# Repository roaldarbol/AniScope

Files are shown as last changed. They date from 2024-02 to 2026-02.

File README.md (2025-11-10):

<h1 align="center">AniScope</h1>
<p align="center">



</p>

<p align="center">
  
</p>
<p align="center">
  <b>A modular ethoscope for customised behavioural experiments with tiny animals.</b><br>
</p>

# Features
Due to its modular design, AniScope is easy to modify:
- Easy customization with the OpenSCAD Customizer
- Create and use presets
- Multiple arenas available
- Goes hand-in-hand with [BeeHive](https://github.com/BeeHive-org/BeeHive) for electronics

# Quick start
1. [Download OpenSCAD](https://openscad.org/downloads.html)
2. Download this repository
    - *From Github: click `Code`->`Download Zip`*
    - *From command line: `git clone https://github.com/roaldarbol/AniScope.git`*
3. Open OpenSCAD
4. Open `aniscope.scad`
5. Enable the Customizer
    - `Window` -> `Customizer`
6. For the best experience, change `Show description`to `Description only`. 

# Acknowledgements
The term ethoscope was coined by Quentin Geissman and Giorgio Gilestro (see their [Ethoscope](https://giorgiogilestro.notion.site/giorgiogilestro/Ethoscope-User-Manual-a9739373ae9f4840aa45b277f2f0e3a7)). The philosophy behind the modularity also takes great inspiration from the [UC2](https://github.com/openUC2/UC2-GIT) modular microscope and [BeeHive](https://github.com/BeeHive-org/BeeHive) for electronics.

# Tips
For keeping track of magnet polarities, we recommend the [Magic Magnet tool](https://www.printables.com/model/409283-the-magic-magnet-tool).

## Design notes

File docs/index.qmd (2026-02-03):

<h1 align="center">AniScope</h1>
<p align="center">


</p>

<p align="center">
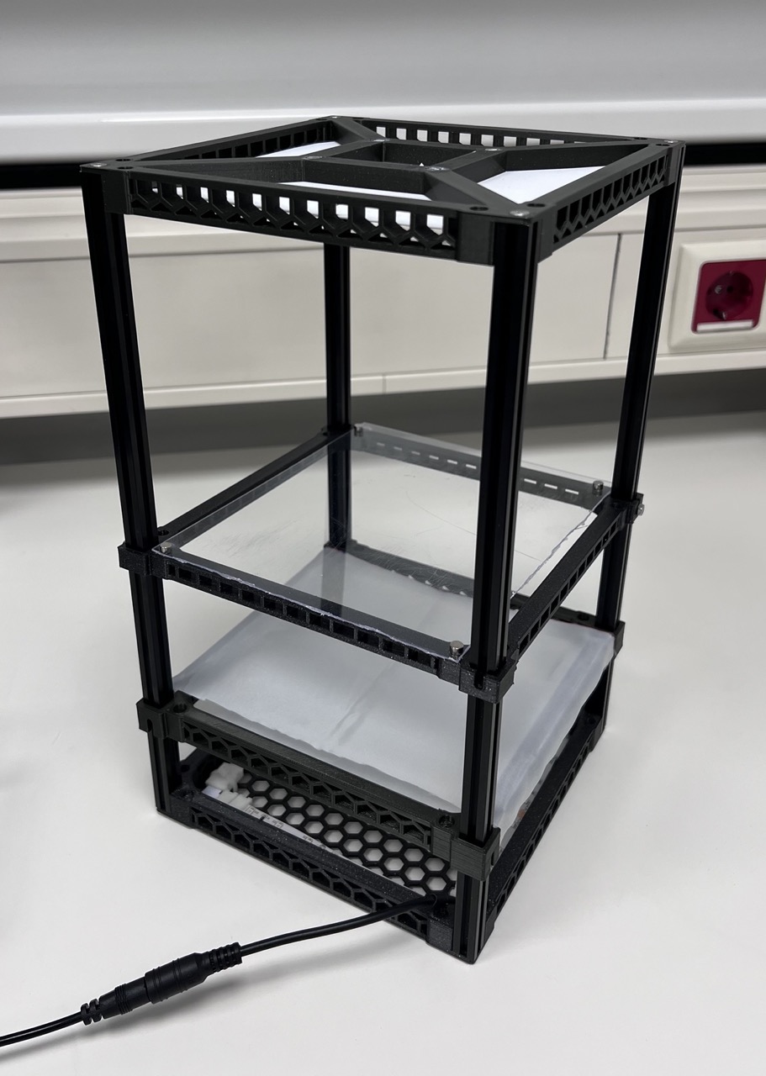
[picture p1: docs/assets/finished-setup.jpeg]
  
</p>
<p align="center">
  <b>A modular ethoscope for customised behavioural experiments with tiny animals.</b><br>
</p>

# Introduction

The AniScope is a modular, 3D-printed imaging arena for tracking small animals (insects, spiders, larvae, etc.). It provides uniform infrared backlighting, adjustable diffusion, and a stable camera mount—all in a compact, customisable package.

# Features
Due to its modular design, AniScope is easy to modify:

- Easy customization with the OpenSCAD Customizer
- Create and use presets
- Multiple arenas available
- Goes hand-in-hand with [BeeHive](https://github.com/BeeHive-org/BeeHive) for electronics

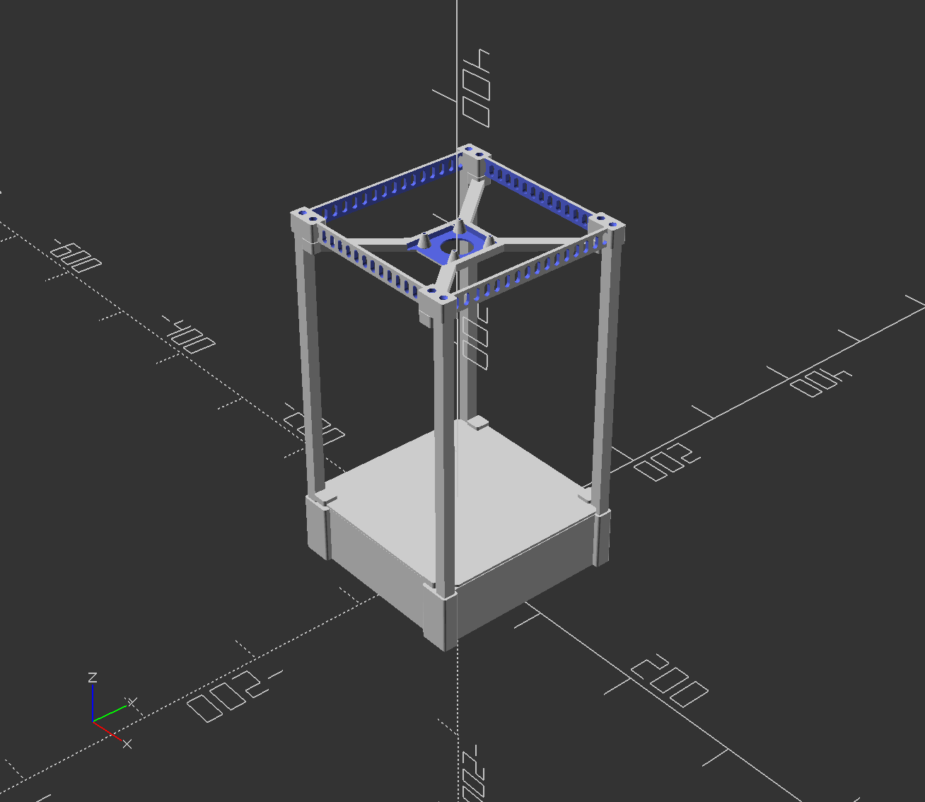
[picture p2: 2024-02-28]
aniscope.png

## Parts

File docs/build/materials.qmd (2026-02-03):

# Bill of Materials

Gather all of the following before you begin. Links are provided for reference; equivalent parts from other suppliers will work.

```{r}
#| echo: false
library(gt)

tibble::tribble(
  ~Category, ~Item, ~Quantity, ~Source, ~Price, ~Notes,
  
  # 3D Printing
  "3D Printing", "3D printer", "1", NA, NA, "Any FDM printer with ≥15 cm build plate",
  "3D Printing", "PLA/PETG filament", "~Xg", NA, NA, "Colour of your choice",
  
  # Structural Components
  "Structural Components", "MakerBeam 30 cm", "4", "[Link](#)", "€X", NA,
  "Structural Components", "MakerBeam tapered bolts", "4", "[Link](#)", "€X", NA,
  "Structural Components", "MakerBeam standard bolts", "8", "[Link](#)", "€X", NA,
  "Structural Components", "MakerBeam nuts", "X", "[Link](#)", "€X", NA,
  
  # Lighting
  "Lighting", "IR LED strip", "1 roll", NA, NA, "850 nm or 940 nm; need 40 cm total",
  "Lighting", "End click connector", "1", NA, NA, "Must match strip width",
  "Lighting", "Corner click connectors", "3", NA, NA, "Must match strip width",
  "Lighting", "12V power supply", "1", NA, NA, "For LED strips",
  
  # Assembly Supplies
  "Assembly Supplies", "Neodymium magnets (Ø6 x 2 mm)", "X", NA, NA, "Quantity depends on configuration",
  "Assembly Supplies", "Superglue (cyanoacrylate)", "1", NA, NA, "Gorilla Glue or similar",
  "Assembly Supplies", "Diffuser fabric", "1 piece", NA, NA, "White ripstop nylon or similar; ~20 x 15 cm",
  "Assembly Supplies", "Small cable ties", "~10", NA, NA, "For cable management",
  "Assembly Supplies", "Disposable gloves", "1 pair", NA, NA, "Nitrile or latex",
  "Assembly Supplies", "Paper towels", "A few sheets", NA, NA, "For wiping excess glue",
  "Assembly Supplies", "Stanley knife / scissors", "1", NA, NA, "For cutting LED strips and fabric"
) |>
  gt(groupname_col = "Category") |>
  fmt_markdown(columns = c(Item, Source)) |>
  sub_missing(missing_text = "") |>
  cols_label(
    Item = "Item",
    Quantity = "Quantity",
    Source = "Source",
    Price = "Approx. Price",
    Notes = "Notes"
  ) |>
  tab_style(
    style = list(
      cell_fill(color = "#f5f5f5"),
      cell_text(weight = "bold")
    ),
    locations = cells_row_groups()
  ) |>
  tab_style(
    style = cell_borders(sides = "bottom", color = "#d3d3d3", weight = px(1)),
    locations = cells_body()
  ) |>
  tab_options(
    table.width = pct(100),
    row_group.padding = px(10)
  )
```

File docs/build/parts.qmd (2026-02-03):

---
title: Parts & Customisation
---

# Customisation

It is easy to customise the AniScope. Follow these steps:

1. [Download OpenSCAD](https://openscad.org/downloads.html)
2. Download this repository
    - *From Github: click `Code`->`Download Zip`*
    - *From command line: `git clone https://github.com/roaldarbol/AniScope.git`*
3. Open OpenSCAD
4. Open `aniscope.scad`
5. Enable the Customizer
    - `Window` -> `Customizer`
6. For the best experience, change `Show description`to `Description only`. 

# Parts

Here we show a list of the different components that can be used with the AniScope. 

| Part | Example |
| ---- | --- |
| Camera mount | <iframe src="https://render.githubusercontent.com/view/solid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" width="300" height="300" frameborder="0"></iframe> |

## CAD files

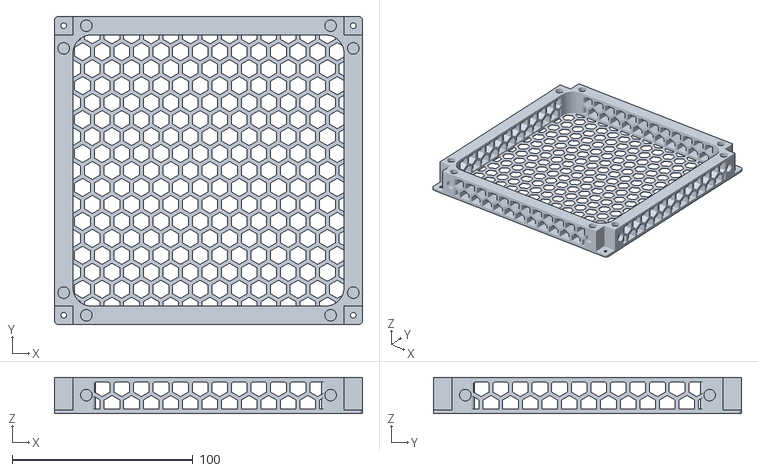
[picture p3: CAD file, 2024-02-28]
examples/01_groundbeetles/frame_hex.stl
170.2 x 170.2 x 20.0

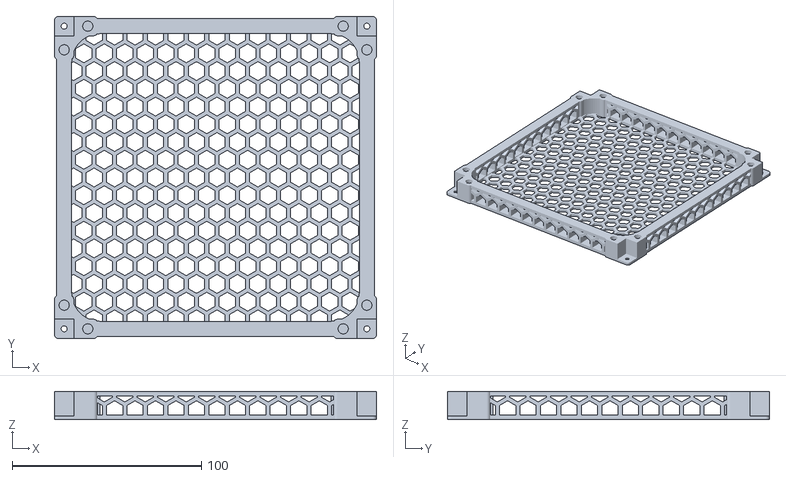
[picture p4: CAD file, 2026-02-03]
examples/default/aniscope-floor-hex.stl
170.2 x 170.2 x 15.0

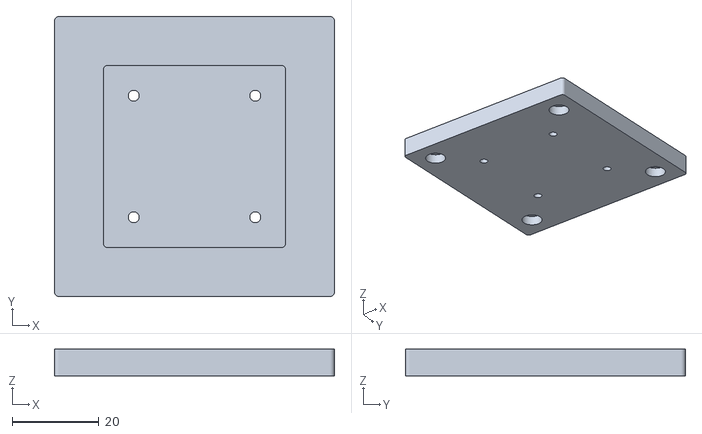
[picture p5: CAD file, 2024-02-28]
examples/01_groundbeetles/adapter_camera_usb.stl
64.5 x 64.5 x 6.20

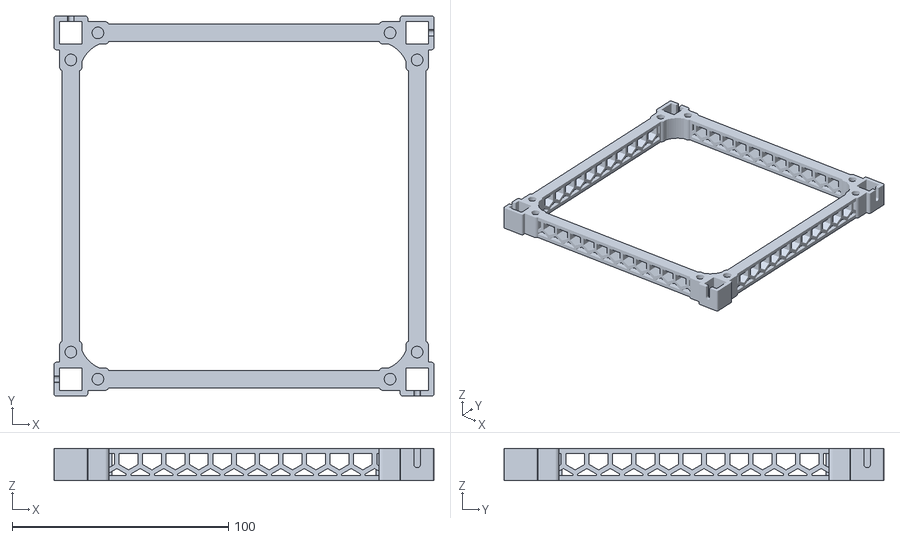
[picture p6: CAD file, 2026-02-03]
examples/default/aniscope-platform-adapter.stl
175.6 x 175.6 x 15.0

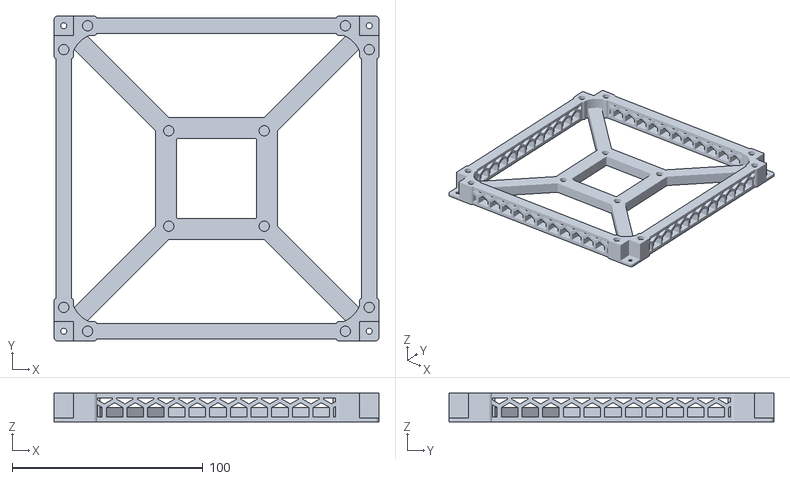
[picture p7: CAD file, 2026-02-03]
examples/default/aniscope-top-xmount.stl
170.2 x 170.2 x 15.0

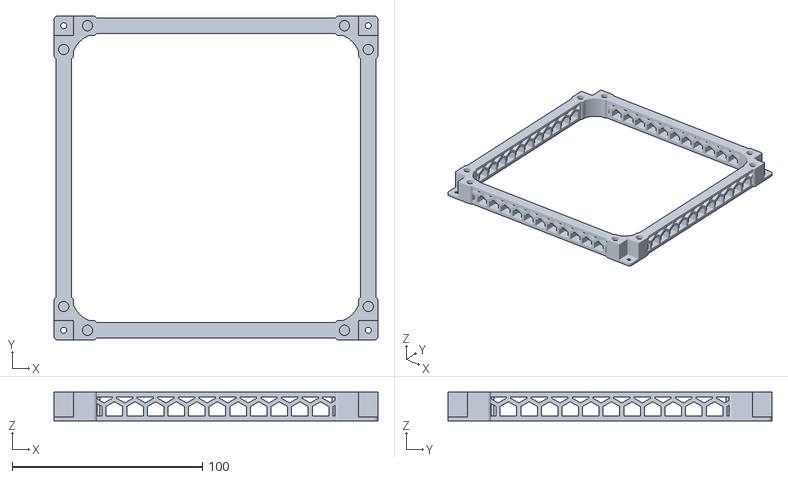
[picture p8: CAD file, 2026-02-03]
examples/default/aniscope-top-empty.stl
170.2 x 170.2 x 15.0

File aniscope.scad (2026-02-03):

// -------------------------------- //
// ----- Import dependencies ------ //
// -------------------------------- //

use <parts/core/core.scad>;
use <parts/adapters/adapters.scad>;
use <parts/platforms/platforms.scad>;
use <parts/frame/frame.scad>;
use <parts/frame/platform_adapter.scad>;
use <parts/misc/misc.scad>;


// -------------------------------- //
// ---------- Variables ----------- //
// -------------------------------- //

$fn = $preview ? 60 : 60;

/* [Assembly] */
// Which part to render?
part = "frame"; // [frame: Frame, platform_adapter: Platform adapter, platform_mount: Platform mount, platform_empty: Platform (empty), platform_diffuser: Platform (diffuser), platform_tubes: Platform (tubes), platform_petri: Platform (Petri dishes), platform_wellplate: Platform (wellplate), x_mount: X-mount, adapter_empty: Adapter empty, cam_adapter: Adapter camera, cam_adapter_elp: Adapter camera (ELP), adapter_breakoutgarden: Adapter Breakout Garden, adapter_neopixel: Adapter Neopixel, adapter_neopixel_lid: Adapter Neopixel lid, tube_plug: Tube plug, tube_floor: Tube floor]

// What is a tube insert?

/* [Frame] */
// Ethoscope dimensions (length, width, height)
dims = [160,160,15]; //normal length
// Thickness of the wall
wall_thick = 8; 
// Which T-slots are used?
makerbeam = 10.2; // [10.2: Makerbeam, 15.2: MakerbeamXL]
// Magnet size (diameter, height)
magnet_size = [6,3];
magnet_size_corrected = magnet_size_correct(magnet_size);
// Floor type
frame_floor_type = "none"; // [none: None, hex: Hex, x: X-mount]

/* [Platform dimensions] */
// Dimensions, preference chamber (diameter, height, gap width)
chamber_dims = [100,20,20]; 
// Dimensions, wellplate (length, width, height)
wellplate_dims = [127.63,85.47,2]; 
// Dimensions, glass tubes (outer diameter, length)
glass_tube_dims = [20.5, 130];

/* [Camera] */
// Number of cameras
n_cams = 2; // [1:1:2]
// Type of camera
Camera_type = "usb"; // [usb: USB, rpi: Raspberry Pi]
// Camera bolt diameter
Camera_screw = 2; // Bolt used to attach cameras
// Magnet placement on adapter
adapter_magnet_orientation = "bottom"; // [bottom: Bottom, top: Top]
// Diameter of hole for lens (0 for no hole)
lens_hole_diam = 0; // [0:1:30]

/* [Acrylic tubes] */
// Dimensions, acrylic tubes (outer diameter, thickness, length)
acrylic_tube_dims = [30, 2, 100]; 
// O-ring diameter
o_ring_diam = 2.5; // Diameter of the O-ring
o_ring_dims = [acrylic_tube_dims[0], o_ring_diam];
// Type of tube plug
tube_plug = "flush"; // [flush: Flush, funnel: Funneled, with_floor: With floor, with_anchor: With anchor-point]
// Plug: Hose connector thread (diameter)
hose_connector_d = 10; 
// Plug: Hose connector position
connector_position = "end"; // [end: End of tube, side: Side of tube]

/* [Petri dishes] */
// Dimensions of Petri dishes (diameter, height)
petri_dish_dims = [60, 20];

/* [Misc] */
// NeoPixel diffuser
lid_thickness = 10;
// Misc for visualization
beam_height = 300;
// Target diameter
target_diam = 7;

/* [Hidden] */
light_chamber_dims = [dims[0],dims[1],40];
platform_dims = [dims[0],dims[1],3];
magnet_dims = [dims[0]-25,dims[1],magnet_size_corrected[1]];
x_mount_dims = [dims[0]-25,dims[1], magnet_size_corrected[1]*2 + wall_thick/2];
adapter_magnet_dims = [50,50,magnet_size_corrected[1]*2+wall_thick]; // Size of the mount
primary_bolt = 3; // Bolt used in MakerBeams
usb_hole_distances = [
    ["rpi", [21,13.5]],
    ["usb", [28,28]]
]; // USB: [28,28] - RPi: [21,13.5];
adapter_hole_positions = selector(Camera_type, usb_hole_distances);
pos_holes = get_points(adapter_hole_positions[1]);

// Hidden tube params
// Parameters: [with_funnel, with_floor, with_anchor]
tube_parameters = [
    ["flush", [false,false,false]], 
    ["funnel", [true,false,false]],
    ["with_floor", [true,true,false]],
    ["with_anchor", [false,false,true]]
]; 
// Plug: Carve out funnel?
include_funnel = selector(tube_plug, tube_parameters)[1][0];
// Plug: Include space for floor (only works with funnel)
include_floor = selector(tube_plug, tube_parameters)[1][1];
// Plug: Include space for floor (only works with funnel)
include_anchor = selector(tube_plug, tube_parameters)[1][2];

// -------------------------------- //
// --------- Compile model -------- //
// -------------------------------- //

print_part();

// We create a loooooong function that enables us to create all our models from the customizer.
module print_part() {
    // Base without floor
	if (part == "frame") {
        frame(
            dims = dims, 
            magnet_pos = magnet_dims, 
            makerbeam = makerbeam, 
            wall_type = "hex",
            wall_thick = wall_thick, 
            magnet_size = magnet_size_corrected, 
            bolt_diam = primary_bolt,
            floor_type = frame_floor_type,
            floor_thick = 2,
            adapter_magnet_dims = adapter_magnet_dims
        );
    } else if (part == "platform_adapter") {
        rotate([180,0,0])
        platform_adapter(
            dims = dims, 
            magnet_pos = magnet_dims, 
            makerbeam = makerbeam, 
            wall_type = "hex",
            wall_thick = wall_thick, 
            magnet_size = magnet_size_corrected, 
            bolt_diam = primary_bolt,
            adapter_magnet_dims = adapter_magnet_dims
        );
	} else if (part == "platform_mount") {
        platform_mount(
            makerbeam = makerbeam,
            magnet_size = magnet_size_corrected,
            wall_thick = 3,
            bolt_diam = primary_bolt
        );
    } else if (part == "platform_empty") {
        platform_empty(
            dims = platform_dims, 
            magnet_dims = magnet_dims,
            magnet_size = magnet_size_corrected,
            makerbeam = makerbeam,
            top_magnets = false
        );
	} else if (part == "platform_diffuser") {
        platform_diffuser(
            dims = platform_dims, 
            magnet_dims = magnet_dims,
            magnet_size = magnet_size_corrected,
            makerbeam = makerbeam
        );
	} else if (part == "platform_tubes") {
		platform_tubes(
            dims = platform_dims, 
            magnet_dims = magnet_dims, 
            magnet_size = magnet_size_corrected, 
            tube_dims = acrylic_tube_dims,
            o_ring_dims = o_ring_dims,
            makerbeam = makerbeam
        );
    } else if (part == "platform_wellplate") {
        platform_wellplate(
            dims = platform_dims, 
            magnet_dims = magnet_dims, 
            wellplate_dims = wellplate_dims,
            magnet_size = magnet_size_corrected, 
            makerbeam = makerbeam
        );
    } else if (part == "platform_petri") {
		platform_petri(
            dims = platform_dims, 
            magnet_dims = magnet_dims, 
            magnet_size = magnet_size_corrected, 
            makerbeam = makerbeam,
            dish_dims = petri_dish_dims
        );
    } else if (part == "x_mount") {
        x_mount(
            dims = x_mount_dims,
            makerbeam = makerbeam,
            wall_thick = 6, 
            magnet_size = magnet_size_corrected,
            adapter_magnet_dims = adapter_magnet_dims
        );
    } else if (part == "adapter_empty") {
        adapter_empty(
            n=1,
            dims = magnet_dims,
            makerbeam = makerbeam,
            wall_thick = 3,
            magnet_pos = adapter_magnet_orientation,
            magnet_size = magnet_size_corrected, 
            adapter_magnet_dims = adapter_magnet_dims
        );
    } else if (part == "cam_adapter") {
        adapter_usb_cam(
            n_cams = n_cams,
            dims = magnet_dims,
            makerbeam = makerbeam,
            wall_thick = 3, 
            magnet_pos = adapter_magnet_orientation,
            magnet_size = magnet_size_corrected,
            bolt_diam = 2.5,
            adapter_magnet_dims = adapter_magnet_dims,
            usb_hole_positions = pos_holes,
            lens_hole_diam = lens_hole_diam
            );
    } else if (part == "cam_adapter_elp") {
        adapter_usb_elp(
            n_cams = n_cams,
            dims = magnet_dims,
            makerbeam = makerbeam,
            wall_thick = 3, 
            magnet_pos = adapter_magnet_orientation,
            magnet_size = magnet_size_corrected,
            adapter_magnet_dims = adapter_magnet_dims,
            );
    } else if (part == "adapter_breakoutgarden") {
        adapter_breakoutgarden(
            dims = magnet_dims,
            makerbeam = makerbeam,
            wall_thick = 3,
            magnet_pos = adapter_magnet_orientation,
            magnet_size = magnet_size, 
            adapter_magnet_dims = adapter_magnet_dims
        );
	} else if (part=="adapter_neopixel") {
        adapter_neopixel(
            dims = magnet_dims,
            makerbeam=10,
            wall_thick=3,
            magnet_pos="bottom",
            magnet_size = magnet_size, 
            adapter_magnet_dims = adapter_magnet_dims, 
            bolt_diam = 2.5,
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

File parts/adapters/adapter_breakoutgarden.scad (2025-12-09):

use <../core/core.scad>;
use <adapter_empty.scad>;

module adapter_breakoutgarden(
    dims,
    makerbeam=10,
    wall_thick=3,
    magnet_pos="bottom",
    magnet_size, 
    adapter_magnet_dims
 ) {
    // Base adapter
    adapter_empty(
        n=1,
        dims,
        makerbeam,
        wall_thick,
        magnet_pos,
        magnet_size, 
        adapter_magnet_dims
    );
    height = magnet_size[1]+wall_thick;
    board_dims = [103, 65, 1.5];
    board_container_dims = [
        board_dims[0] + 4,
        board_dims[1] + 4,
        board_dims[2] + 4
        ];
    translate([0,0,(height + board_container_dims[2]) / 2])
    difference(){
        // Top piece
        rounded_cube(dims = board_container_dims, radius = 1, outside = false, $fn = 60);

        translate([(board_container_dims[0]-board_dims[0]) / 2,0,0]){
            // Board itself
            rounded_cube(dims = board_dims, radius = 1, outside = false, $fn = 60);
        
            // Center cutout
            translate([2.5,0,0])
            rounded_cube([board_dims[0]+5, board_dims[1]-10, board_container_dims[2]*1.1], radius = 0.1);
        }
    } 
 }

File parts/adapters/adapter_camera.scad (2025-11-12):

use <../core/core.scad>;

module adapter_usb_cam(
    n_cams=1,
    dims,
    makerbeam=10,
    wall_thick=3,
    magnet_pos="bottom",
    magnet_size, 
    adapter_magnet_dims, 
    bolt_diam,
    usb_hole_positions,
    lens_hole_diam
 ) {
    
    adapter_magnet_dims_low = [adapter_magnet_dims[0],adapter_magnet_dims[1], magnet_size[1]];
   
    difference(){
        union(){
            rounded_cube([(n_cams*adapter_magnet_dims[0])+12.5,adapter_magnet_dims[1]+12.5,magnet_size[1]+wall_thick]);
        }
        
        if (magnet_pos=="bottom"){
            translate([0,0,-(magnet_size[1]/2+wall_thick/2)]){
                // Bottom center magnets
                magnets2(adapter_magnet_dims, magnet_size, wall_thick);
                mirror([1,0,0]) magnets2(adapter_magnet_dims, magnet_size, wall_thick);
            }
        }
        
        if (magnet_pos=="top"){
            // Top center magnets
            translate([0,0,-(magnet_size[1]-wall_thick)/2]){
                magnets2(adapter_magnet_dims, magnet_size, wall_thick);
                mirror([1,0,0]) magnets2(adapter_magnet_dims, magnet_size, wall_thick);
            }
        }
      
        translate([0,0,wall_thick])
        rounded_cube([n_cams*adapter_magnet_dims[0]-10,adapter_magnet_dims[1]-10,dims[2]]);
        
        if (n_cams==1){
            translate([0,0,-3*1.5])
            for (j=[0,1]){
                rotate([0,0,j*90])
                for(k=usb_hole_positions){
                        translate([k[0], k[1],0])
                        cylinder(d=bolt_diam, h=wall_thick*4);
                }
            }
            // Lens
            cylinder(d=lens_hole_diam, h=dims[2]*4, center = true);
        } else if (n_cams==2){
            for (i = [-1,1]){
                translate([i*adapter_magnet_dims[0]/2,0,0]){
                    for (j=[0,1]){
                        rotate([0,0,j*90])
                        for(k=usb_hole_positions){
                                translate([k[0], k[1],0])
                                cylinder(d=bolt_diam, h=wall_thick*4, center = true);
                        }
                    }
                // Lens
                cylinder(d=lens_hole_diam, h=dims[2]*4, center = true);
                }
            }
        }
    }
}

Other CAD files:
parts/adapters/adapter_camera_elp.scad
parts/adapters/adapter_empty.scad
parts/adapters/adapter_neopixel.scad
parts/adapters/adapters.scad
parts/adapters/xmount.scad
parts/arenas/arena_preference.scad
parts/arenas/arena_respirometry.scad
parts/arenas/arena_tubes.scad
parts/arenas/arena_vertical.scad
parts/arenas/arena_wellplate.scad
parts/core/core.scad
parts/core/corners.scad
parts/core/cross.scad
parts/core/functions.scad
parts/core/hex.scad
parts/core/magnets.scad
parts/core/makerbeam.scad
parts/core/o_ring.scad
parts/core/rounded_cube.scad
parts/core/standoffs.scad
parts/frame/floor.scad
parts/frame/frame.scad
parts/frame/platform_adapter.scad
parts/frame/wall.scad
parts/misc/beam_slider.scad
parts/misc/misc.scad
parts/misc/misc_hose_connectors.scad
parts/misc/platform_mount.scad
parts/misc/tube_fittings.scad
parts/platforms/ethoscope_arenas.scad
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

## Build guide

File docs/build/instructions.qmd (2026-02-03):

# Overview

**Difficulty:** Beginner–Intermediate  
**Build time:** 1-2 hours (excluding 3D printing)  
**3D printing time:** Approximately 20 hours (varies by printer)  
**Estimated cost:** €XX–€XX (excluding camera and 3D printer)

> **Before you start:** Read each section to the end before beginning it. This helps you understand what's coming and ensures you have everything ready. Printing the 3D parts may take a couple of days on a single printer—plan accordingly.

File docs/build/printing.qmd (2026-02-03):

## 3D Printing

Print the following parts. STL files are available at [link].

| Part | Quantity | Infill | Supports | Print Time |
|---|---|---|---|---|
| Bottom piece (with grid) | 1 | 20% | No | ~X hrs |
| Top piece | 1 | 20% | No | ~5 hrs |
| Top piece, empty | 1 | 15% | No | ~5 hrs |
| Diffuser frame | 1 | 20% | No | ~X hrs |
| Camera mount (optional) | 1 | 30% | Yes | ~X hrs |

**Choosing a top piece:**

- **Open top (no centre):** Best for DSLR on a tripod or other external mount
- **X-mount top:** Best for USB cameras with a dedicated camera attachment

**Optional but recommended:** Print the [magnet insertion handles](link-to-file)—they make magnet installation much easier.

Print settings:

- Nozzle: 0.4
- Layer height: 0.2 mm
- No skirt (0 mm)
- Brim: 3 mm

::: {layout-ncol=2}

:::: {#fig-camera-adapter}
Camera mount

<iframe src="https://render.githubusercontent.com/view/solid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" width="100%" height="300" frameborder="0"></iframe>
::::

:::: {#fig-camera-adapter-2}
Camera mount 2
<iframe src="https://render.githubusercontent.com/view/solid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" width="100%" height="300" frameborder="0"></iframe>
::::

:::

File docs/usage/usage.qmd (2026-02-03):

# How to Use the AniScope

*[This section to be completed—cover topics such as:]*

- Positioning subjects in the arena
- Adjusting lighting intensity
- Camera settings for optimal tracking
- Software integration (if applicable)
- Cleaning and maintenance

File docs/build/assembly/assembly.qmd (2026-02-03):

## Assembly

## Notes and Tips

- **More diffusion needed?** Add a second diffuser layer, or use a second diffuser frame with fabric at a different height.
- **Custom arena sizes:** The design is parametric—see [link] to generate parts for different dimensions.
- **Filament choice:** PLA works fine for most uses. PETG is more durable if you expect rough handling.

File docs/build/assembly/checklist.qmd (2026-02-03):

## Checklist

- [ ] All magnets secure and properly polarised
- [ ] LED strips illuminate evenly
- [ ] Diffuser fabric taut and wrinkle-free
- [ ] All frame components slide smoothly on rails
- [ ] Camera has clear view of entire arena
- [ ] No loose cables in the imaging area

**Congratulations—your AniScope is ready to use!**

Completed AniScope

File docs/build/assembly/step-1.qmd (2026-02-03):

### 1. Magnets

> **Warning:** Superglue bonds skin instantly. Wear gloves throughout this step, and have paper towels within reach to wipe up excess glue immediately.

> **Read this entire step before starting.** Once glue is applied, you have only a few seconds to position the magnet.

#### Decide on magnet polarity

All magnets in **upward-facing holes** should have the same pole facing up. All magnets in **downward-facing holes** should have the opposite pole facing up. This ensures parts attach correctly later. The [**Magic Magnet Tool**](https://www.printables.com/model/442051-the-magic-magnet-tool-small-size) makes this easy by providing a tool for each.

#### Install each magnet

1. Place a magnet on the insertion tool (or hold carefully with gloved fingers), correct pole facing outward.
2. Apply a small drop of superglue into the hole.
3. Press the magnet firmly into the hole.
4. If using the tool, slide it sideways while holding the magnet in place with your other hand.
5. Immediately wipe away any excess glue with paper towel.
6. Repeat for all required holes.

**Wait at least 5 minutes** before bringing other magnets near—the glue needs time to cure, and magnetic attraction can pull magnets out of wet glue.

Magnet installation

**Checkpoint:** Magnets should sit flush with or slightly below the surface. Test with a loose magnet—it should snap firmly into place from ~1 cm away.

### Attach magnets to diffuser

1. Orient the diffuser frame so the **corner grooves face upward**.
2. Flip it over—you'll attach magnets to the **bottom** (the side now facing up).
3. Install magnets in the four corner holes using the same technique as Step 1.
4. Ensure polarity is correct: these magnets must attract the bottom piece's magnets.

**Checkpoint:** Place the diffuser frame on the bottom piece. It should click into place magnetically and sit flat.

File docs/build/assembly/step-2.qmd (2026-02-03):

### 2. LED Strips

> **Warning:** When stripping waterproof strips, remove only the silicone coating, ensuring not to cut the strip itself.

> **Warning:** Do not lift the metal contacts inside the click connectors. This causes loose connections that are difficult to fix.

1. Cut **4 segments** from the LED strip roll, each **2 LEDs long** (~10 cm). Cut only on the marked lines.
2. If using waterproof strips: carefully trim ~1 cm of silicone coating from each end to expose the contacts.
3. Open a **corner connector** by lifting the plastic flaps.
4. Insert one strip, matching **+** to **+** and **−** to **−**.
5. Close the flap firmly.
6. Repeat, connecting all four strips with three corner connectors to form a square.
7. Attach the **end connector** to one remaining strip end for power.
8. Place the **LED strip assembly** into the bottom piece's floor. 
9. Use small cable ties to secure across the connectors and in the middle of each segment.

LED strip assembly diagram

**Checkpoint:** Connect to 12V power briefly. All four strips should illuminate evenly - this may not be visible by eye, instead point an IR-sensitive camera at the strips to see whether they light up. If any strip is dim or off, check that connector's contacts.

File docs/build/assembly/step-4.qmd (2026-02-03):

### 4. Diffuser Fabric

1. Cut a piece of diffuser fabric approximately **20 cm × 15 cm** (exact size is not critical; it just needs to cover the frame with ~2 cm overhang on each side).
2. Place the diffuser frame groove-side up.
3. Lay the fabric over the top.
4. On one short end, fold the fabric underneath and secure with **2 spare magnets** on the underside.
5. Pull the fabric taut across the top.
6. Fold the opposite end underneath and secure with 2 more magnets.

**Checkpoint:** The fabric should be taut with no wrinkles. When held up to light, it should appear evenly translucent.

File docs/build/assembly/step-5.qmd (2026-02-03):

### 5. Assemble

1. Take the **4 MakerBeam 30 cm rails** and **4 tapered bolts**.
2. Screw a tapered bolt into each corner hole of the **bottom piece**. The rails should point upward.
3. Slide the **diffuser frame** down the rails from above.
4. On the sides with grooves, slide a **standard bolt** into the MakerBeam slot.
5. Adjust the diffuser to your desired height, then tighten the bolt with a nut to lock it in place.
6. (Optional) If using multiple diffusers, add them the same way at different heights.
7. Slide the **arena** down the rails and secure at the desired height.
8. Attach the **top piece** to the rail tops using the remaining tapered bolts.

Frame assembly

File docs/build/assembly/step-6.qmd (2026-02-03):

### 6. Camera

If using a **USB camera** with the X-mount top:

1. Attach the camera to the printed camera mount.
2. Slide the mount into the X-shaped slot on the top piece.
3. Secure with magnets or bolts as appropriate for your mount design.

If using a **DSLR or external camera:**

1. Position your tripod over the AniScope, looking down through the open top.
2. Adjust tripod height so the arena fills the camera's field of view.

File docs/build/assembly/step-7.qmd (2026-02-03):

### 7. Power

1. Connect the LED strip's power cable to your 12V supply.
2. Power on and verify all LEDs illuminate.
3. If using IR LEDs, you can verify operation with an IR camera (most cameras cannot see near-IR light).

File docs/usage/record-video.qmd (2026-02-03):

[OBS](https://obsproject.com/da) or [Bonsai](https://bonsai-rx.org/)

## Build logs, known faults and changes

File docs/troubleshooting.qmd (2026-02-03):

# Troubleshooting

| Problem | Possible Cause | Solution |
|---|---|---|
| LEDs don't light up | Loose connector | Reopen connector, ensure contacts align, close firmly |
| Uneven lighting | Diffuser not taut; LED segment out | Check fabric tension; check each LED segment individually |
| Magnets won't hold | Wrong polarity | Check orientation; you may need to remove and reinstall |
| Magnet fell out | Insufficient glue / pulled out before curing | Re-glue with fresh superglue; wait longer before testing |
| Camera image is blurry | Wrong focal distance; dirty lens | Adjust camera height; clean lens and diffuser |
| IR light not visible | LEDs not powered; camera can't see IR | Check power; test with phone camera |

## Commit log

2025-11-10 Beginning to properly clean up
    [aniscope.scad, arena_empty.scad, arena_spacer.scad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]
2025-11-12 Updates to adapters and platforms
    [adapter_camera.scad, adapter_neopixel.scad, aniscope.scad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]
2025-11-13 Petri dish finished
    [platform_petri.scad]
2025-11-13 Add empty and breakout garden adapters
    [adapter_breakoutgarden.scad, adapter_empty.scad, adapters.scad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]
2025-12-09 Make initial camera adapter
    [adapter_breakoutgarden.scad, adapter_camera_elp.scad, adapters.scad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]
2026-02-03 Big unfinished docs update
    [adapter_camera_elp.scad, aniscope-floor-hex.stl, aniscope-platform-adapter.stl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]
